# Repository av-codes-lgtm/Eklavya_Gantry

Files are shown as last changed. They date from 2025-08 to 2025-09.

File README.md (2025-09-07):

# **GantryMate-200: Automated Gantry-Based Screwing System**
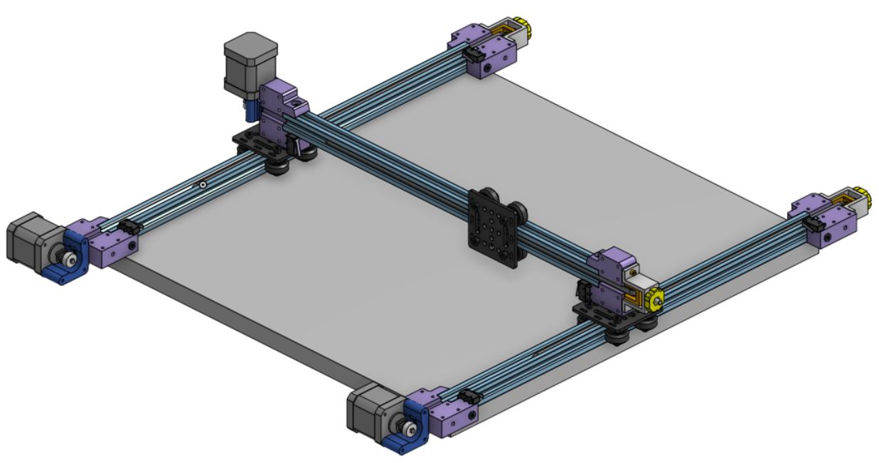
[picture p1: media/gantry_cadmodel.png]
whole assembly_withouttoolhead
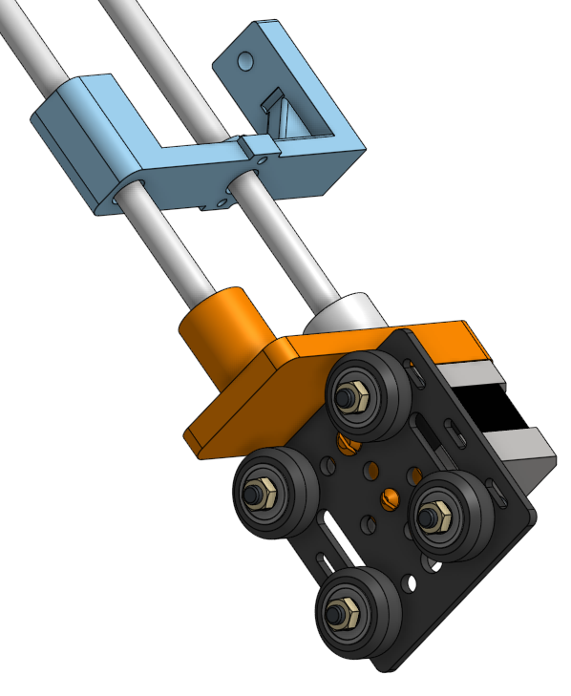
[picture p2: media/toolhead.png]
Toolhead 3d files
|||
:-------------------------:|:-------------------------:|

<p align="center">
  
</p>

## Table of Contents
1. [Problem Statement](#problem-statement)
2. [Our Solution](#our-solution)
   - [LED Panel Configuration](#led-panel-configuration)
   - [Critical Requirements](#critical-requirements)
3. [Features](#features)
4. [Prerequisites](#prerequisites)
5. [Repository Structure](#repository-structure)
6. [Installing](#installing)
7. [Hardware Architecture](#hardware-architecture)
8. [Future Goals](#future-goals)
9. [Authors](#authors)
10. [Acknowledgments](#acknowledgments)

---

## Problem Statement

**GantryMate-200** addresses the challenge of automating the precise handling of **~280 miniature screws (1 mm size)** on sensitive LED panels. The system must operate with extreme precision around delicate circuitry while maintaining high-speed performance.

## Our Solution

An advanced automated gantry system designed for precision screwing and unscrewing of miniature screws on delicate LED panels with sub-millimeter accuracy and high-speed operation.

[CAD MODEL](https://cad.onshape.com/documents/f8e877963d969bd52a009480/w/ae625ac84bd115da8b87aa91/e/6dbc831cc6b275fe37f96716) (Our CAD files)

### LED Panel Configuration

The target LED panel consists of two distinct layers:

* **Top Layer:** Contains **200 screws** - must be removed first during disassembly
* **Bottom Layer:** Contains **80 screws** - accessible only after top layer removal

**Installation Process:** Follows reverse order (bottom layer first, then top layer)

### Critical Requirements

Given the proximity to sensitive circuitry, the system must ensure:

- Sub-millimeter positioning repeatability
- Precise force control to prevent damage
- Accurate screw orientation detection
- Zero tolerance for misalignment
- Complete each screwing/unscrewing operation in **under 5 seconds**

## Features

- **High precision 3-axis gantry system** (X, Y, Z axes)
- **Specialized toolhead** with automated screw feeding mechanism
- **Sub-millimeter(0.05mm resolution) positioning accuracy**
- **High-speed operation** (<5 seconds per screw to be achieved)
- **Automated screw orientation** ensuring correct placement(to be achieved)

### Prerequisites

Hardware requirements:
- ESP32 development board
- DRV8825 stepper motor drivers (3x for X, Y, Z axes)
- Nema 17 Stepper motors (3x for gantry movement)
- Power supply (appropriate voltage/current for your stepper motors)
- Mechanical components (rails, belts, pulleys, frame, etc)

Software used:
- [ESP-IDF](https://docs.espressif.com/projects/esp-idf/en/latest/esp32/get-started/) (development framework) 
- [KiCad](https://www.kicad.org/) (for PCB modifications)
- [Onshape](https://www.onshape.com/) (for Mechanical Design)
- Git for version control.

### Repository Structure

```
Eklavya_Gantry
├── Docs/
├── Firmware/
│   ├── DRV8825/                   #Code for Running the system on DRV8825   
│   │   ├── circle/
│   │   ├── Double_axes/
│   │   ├── final/
│   │   ├── go_to_pos/
│   │   ├── homing/
│   │   ├── limit/
│   │   ├── SRA/
│   │   ├── step_func/
│   │   ├── stepper_test/
│   │   ├── totalhoming/
│   │   └── total_positioning/
│   ├── TMC2208/                   #Code for Running the system on TMC2208
│   │   ├── Go_to_pos/
│   │   ├── step_func/
│   │   └── uart/
│   │       ├── nmea0183_parser/
│   │       ├── uart_async_rxtxtasks/
│   │       ├── uart_echo/
│   │       ├── uart_echo_rs485/
│   │       ├── uart_events/
│   │       ├── uart_repl/
│   │       └── uart_select/
│   └── Screwdriver/               #Code for operating the toolhead
│       └── Screw/
├── Mechanics/
│   .
│   .
│   └── STL files for 3D Printed parts
├── PCB/
|   .
|   .
|   └── KiCad Files for PCB
└── README.md

```

### Installing

Step-by-step setup process:

1. **Clone the repository**
```bash
git clone https://github.com/av-codes-lgtm/Eklavya_Gantry.git
cd Eklavya_Gantry
```

2. **Build and flash firmware**

Go to the folder with the code you want to flash to the esp using 

```bash
cd /Eklavya_Gantry/Firmware/folder-of-your-choice
```

and then run the following code

```bash
idf.py build flash monitor
```

## Hardware Architecture

| Component | Description |
|---|---|
| [ESP32](https://www.espressif.com/en/products/socs/esp32) | Main microcontroller with WiFi/Bluetooth capability |
| [DRV8825 Stepper Drivers](https://www.pololu.com/product/2133) | High-performance microstepping motor drivers |
| Nema 17 Stepper Motors | Precision motors for X, Y, Z axis control |
| Custom PCB | Integrated control and driver circuitry (under development) |

## Future Goals
- Shift to TMC2208 stepper drivers for better current handling and power distribution. DRV8825 does not work for prolonged time periods.
- Finalising the circuitry and shifting completely to PCB.
- Fine tuning the screw in and screw out processes to achieve industry grade quality screwing.
- Add a screw feeding system for the "screwing in" process.
- Creating a feedback mechanism to verify Screwing and unscrewing
- Creating a UI (Either WebPortal or build in software controlled using Raspberry Pi and a small screen) to make operation of the system simpler.
## Authors
*  *Firmware and Hardware setup*- [Aryan_Vyapari](https://github.com/av-codes-lgtm)
*  *PCB Design and tool-head operation* - [Sarvaarth_Narang](https://github.com/SarvaarthN)
*  *Firmware and Hardware setup* - [Pushkar_Dube](https://github.com/pushkardube)  

See the list of [contributors](https://github.com/av-codes-lgtm/Eklavya_Gantry/graphs/contributors) who participated in this project.
## Acknowledgments

* Thanks to the ESP-IDF, KiCad and Onshape community for excellent development tools
* Inspiration from industrial automation and precision manufacturing
- Thanks to our Robotics Club [SRA-VJTI](https://github.com/sra-vjti)  
* Special thanks to our senior mentors [Amey_Tikhe](https://github.com/AmeyaTikhe)  &  [Varun_Nigudkar](https://github.com/fluffysunfish?tab=overview&from=2024-12-01&to=2024-12-31)  

---

**For technical support, feature requests, or bug reports, please open an issue on GitHub.**

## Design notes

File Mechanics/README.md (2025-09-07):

## Mechanics

Stl files of the 3D printed parts & some CAD models

Gantry
toolhead
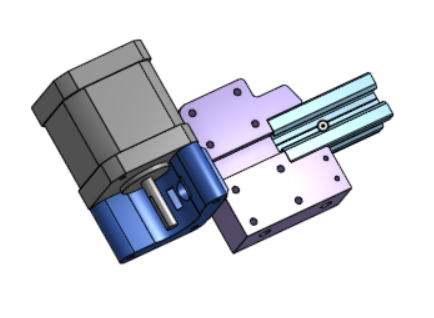
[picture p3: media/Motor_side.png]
motor_supports

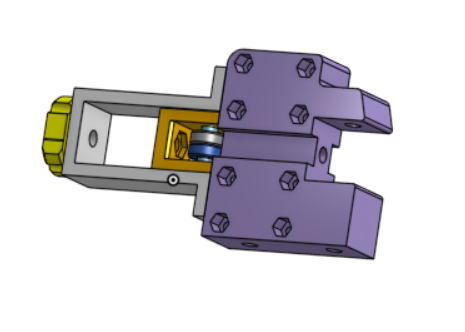
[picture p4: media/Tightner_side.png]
pulley_supports

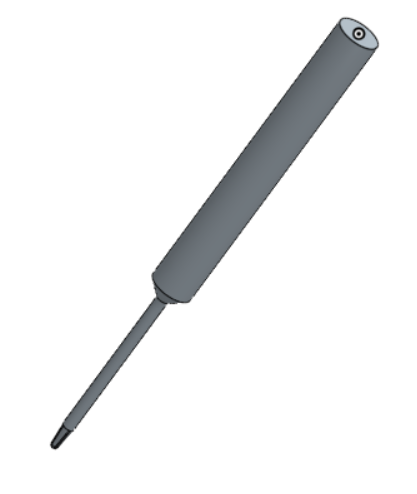
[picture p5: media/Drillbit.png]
Drillbit

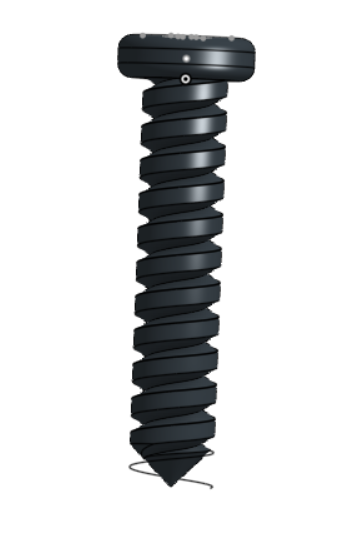
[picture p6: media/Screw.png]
Screws


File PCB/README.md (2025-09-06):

# DRV8825 Stepper Motor Driver with ESP32 and Limit Switch

This project demonstrates how to control a stepper motor using an **ESP32**, a **DRV8825 motor driver**, and a **limit switch** for homing or safety purposes. 
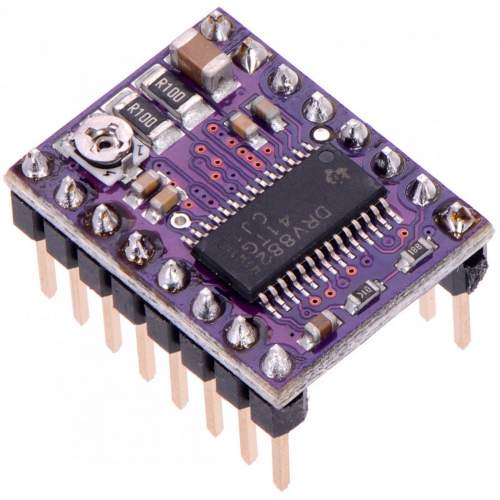
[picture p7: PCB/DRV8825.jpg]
DRV8825 Motor Driver

---

## Circuit Description

The **ESP32** sends step and direction signals to the **DRV8825**, which drives a bipolar stepper motor.  
A **limit switch** is added to detect the end position or provide a safe stop.

---

## Connections

### DRV8825 → Stepper Motor
- **A1, A2, B1, B2** → Connect to stepper motor coils  
  - A coil: A1, A2  
  - B coil: B1, B2  

### DRV8825 → ESP32
- **STEP** → GPIO 18 (pulse to step motor)  
- **DIR** → GPIO 19 (sets rotation direction)  
- **EN (Enable)** → GPIO 21 (active LOW, optional)  
- **GND** → ESP32 GND  
- **VMOT** → External motor supply (8.2–45V depending on motor) but for this Project 12V was used
- **GND (Motor)** → Power supply ground  

**Important:** Place a 100µF electrolytic capacitor across VMOT and GND close to the DRV8825 to protect against voltage spikes.  

### Limit Switch → ESP32
- One terminal → GPIO 23  
- Other terminal → GND  
- Use **internal pull-up resistor** in ESP32 code.  

---

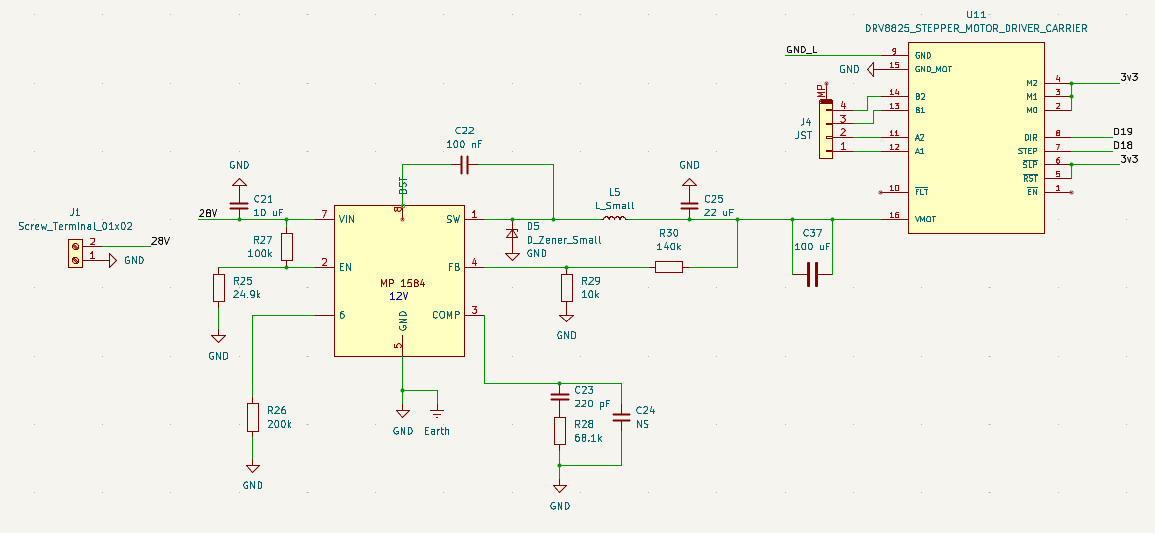
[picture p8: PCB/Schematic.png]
PCB Schematic
 

## Circuit Diagram

```plaintext
              +-------------------+
   VMOT 8-45V |                   | Stepper Motor
   + ---------| VMOT        A1 ---|---- Coil A
   - ---------| GND         A2 ---|---- Coil A
              |                   |
ESP32 GPIO 18 | STEP        B1 ---|---- Coil B
ESP32 GPIO 19 | DIR         B2 ---|---- Coil B
ESP32 GPIO 21 | EN                |
ESP32   GND - | GND               |
              +-------------------+

Limit Switch:
  GPIO 23 ---/ ---- GND

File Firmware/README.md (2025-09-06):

# Gantry Motion Control

This repository contains firmware and test programs for a **3-axis gantry-style screwing machine**, supporting multiple stepper motor drivers (DRV8825 and TMC2208).  
The codebase is organized into modules for motion control, homing, positioning, and testing.

---

## 📂 Repository Structure

### Root Folders
- **.vscode/**  
  VSCode project settings.

- **DRV8825/**  
  Codebase for the gantry using the **DRV8825 stepper driver**.

- **TMC2208/**  
  Codebase for the gantry using the **TMC2208 stepper driver**.

- **Screwdriver/**  
  Code for screwdriver(geared DC motor).
---
### Inside `DRV8825/`

Each driver folder contains multiple subfolders for different functionalities:

- **Double_axes/**  
  Control programs for two axes working together.

- **SRA/**  
  Plots “SRA” on the plane using the gantry

- **circle/**  
  Code for drawing/controlling circular motion.

- **final/**  
  Final stable build for **3-axis gantry motion control**.

- **go_to_pos/**  
  Precise linear positioning of one axis.

- **homing/**  
  Executes homing in one axis.

- **limit/**  
  Test programs for Limit switch functionality.

- **step_func/**  
  Test programs for verifying Acceleration and Deceleration. 

- **stepper_test/**  
  Test programs for verifying stepper motor functionality.

- **total_positioning/**  
  Precise 2D positioning across the plane.

- **totalhoming/**  
  Executes Homing in all axes of the gantry simultaneously

---
### Inside `TMC2208/`

This folder contains code specific to the **TMC2208 stepper driver**:

- **Go_to_pos/**
  Moves the gantry to a specified position.
    
- **step_func/**
  Basic testing for stepper stepping functions.
   
- **uart/**
  UART codes for TMC2208.
---
### Inside `Screwdriver/`

- **Screw/**  
  Contains code for operating a **geared DC motor** (screwdriver mechanism), separate from the stepper-driven gantry system.

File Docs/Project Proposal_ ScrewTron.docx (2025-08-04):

## Project Proposal: ScrewTron – Automated Screwing System for LED Panels

### Problem Statement

The objective is to develop an automated gantry-based system, ScrewTron, capable of screwing and unscrewing approximately 280 miniature screws (1 mm size) on an LED panel efficiently and safely. The system must ensure that each screw is installed or removed in under 5 seconds, while maintaining high precision and avoiding damage to sensitive circuitry.

The panel has two layers:

- The top layer contains 200 screws, which need to be removed first.
- Upon removal, the bottom layer with 80 additional screws becomes accessible.
- The screwing-in process follows the reverse order: the bottom layer is fastened first, followed by the top layer.

Due to the small size of the screws and their close proximity to delicate circuitry, excessive pressure or misalignment can lead to permanent damage. Therefore, the system must prioritize precision, controlled force application, and accurate screw placement and orientation.

### Project Description

The proposed system will feature a high-precision gantry mechanism capable of three-axis motion (X, Y, Z), equipped with a specialized toolhead for screwing/unscrewing operations. A screw feeding mechanism will supply screws to the toolhead in the correct orientation, ensuring uninterrupted operation. The system will be optimized for speed, safety, and accuracy, with the ability to repeat tasks with sub-millimeter precision.

### Key Challenges

1. Screw Feeding Mechanism Designing an efficient feeder that delivers 1 mm screws in the correct orientation to the toolhead without jamming or misalignment.
2. X-Y Gantry Motion Implementing precise and smooth movement across the horizontal plane to position the toolhead at each screw location accurately.
3. Z-Axis Control Ensuring vertical movement of the toolhead is finely controlled to insert or extract screws to the appropriate depth without over-torquing.
4. Time Optimization Ensuring that each screwing/unscrewing operation is completed in less than 5 seconds, keeping the total operation time within practical limits.
5. Toolhead Design and Control Engineering a lightweight, compact, and torque-sensitive toolhead suitable for handling 1 mm screws without damaging surrounding components.

### Major Milestones

- Development of Precision Gantry System Design and implementation of a motion control system with high accuracy in X, Y, and Z directions based on command inputs.
- Design and Testing of Screw Feeder Creation of a reliable mechanism that feeds 1 mm screws in the correct orientation and at appropriate timing.
- Toolhead Integration and Control Design of a screwing/unscrewing toolhead with depth control, torque regulation, and compatibility with the screw feeder.
- System Calibration and Optimization Fine-tuning the system to meet time and precision requirements, ensuring safe operation near delicate electronic components.

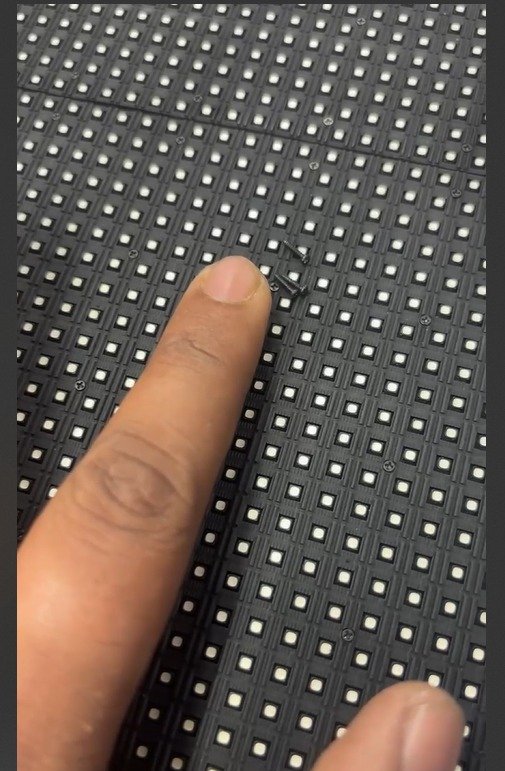
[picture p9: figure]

Video for Reference.mp4 (https://drive.google.com/file/d/1dqILX8j8XaAps2jnEO2ClbA-CurU9LIB/view?usp=sharing)

Only Screwing and unscrewing needs to be automated. Removal of Meshes and frames will be done manually

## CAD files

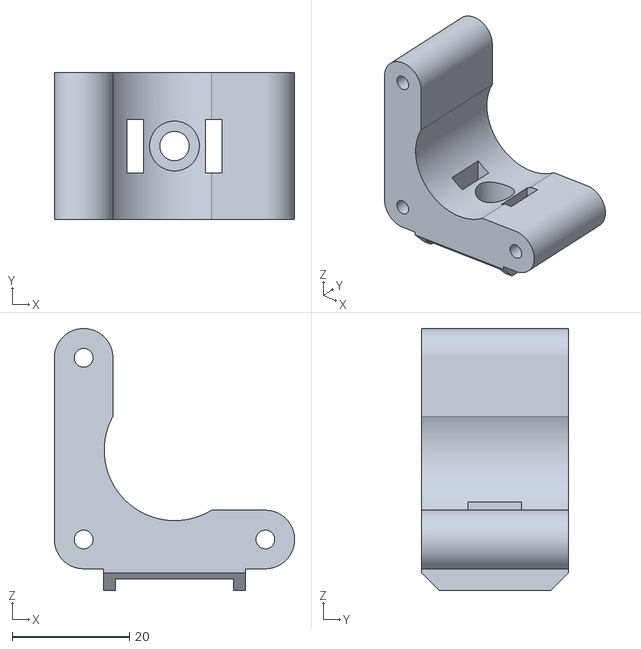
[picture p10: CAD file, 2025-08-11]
Mechanics/x-moteur - support moteur.stl
41.0 x 25.0 x 44.7

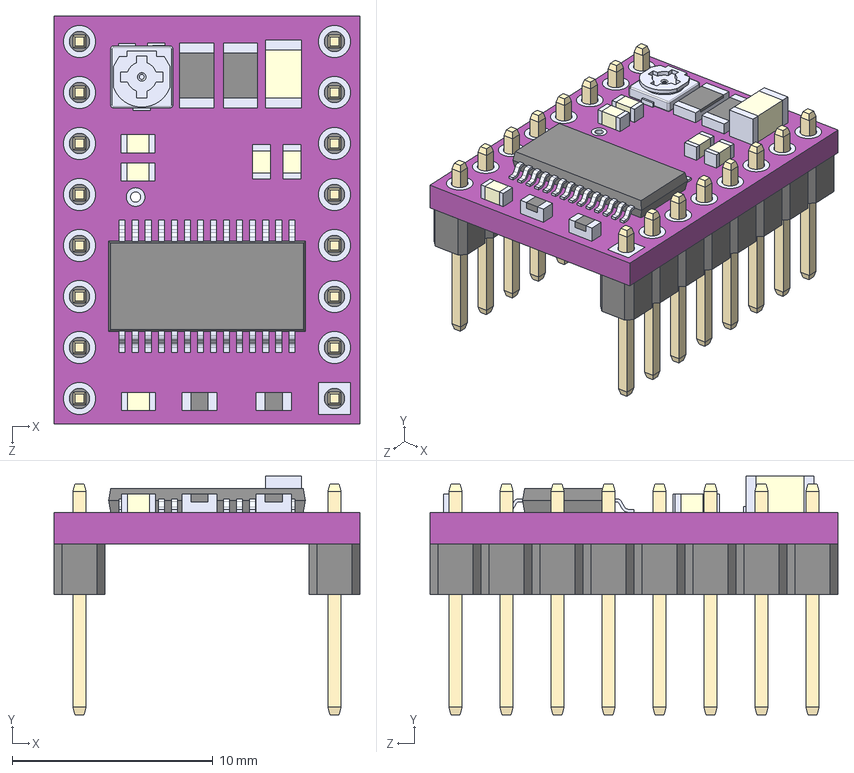
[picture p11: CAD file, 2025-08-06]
PCB/DRV8825_STEPPER_MOTOR_DRIVER_CARRIER.step
15.2 x 11.9 x 20.3 mm

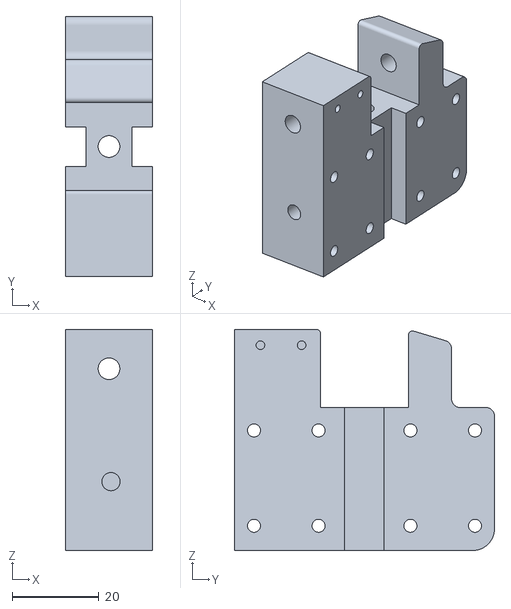
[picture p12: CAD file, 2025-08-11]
Mechanics/x-moteur - support paliers L.stl
20.0 x 60.0 x 51.0

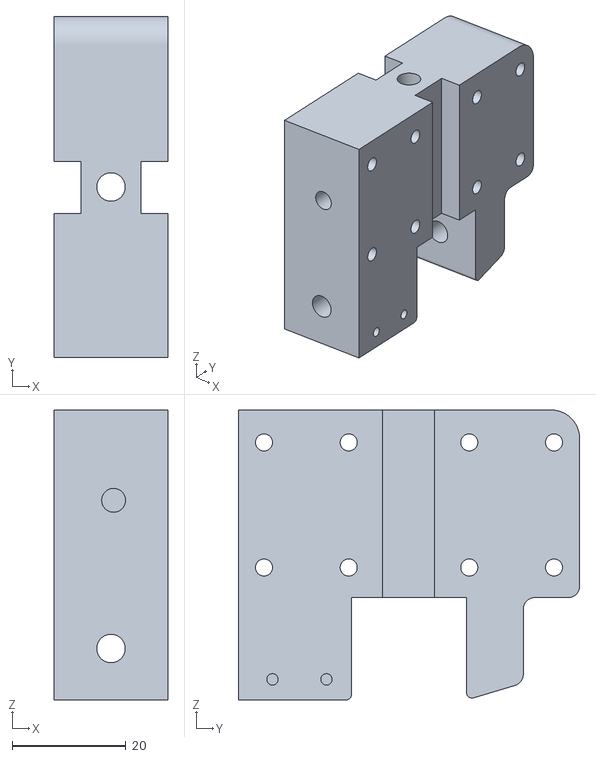
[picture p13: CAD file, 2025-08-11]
Mechanics/x-moteur - support_palier_R.stl
20.0 x 60.0 x 51.0

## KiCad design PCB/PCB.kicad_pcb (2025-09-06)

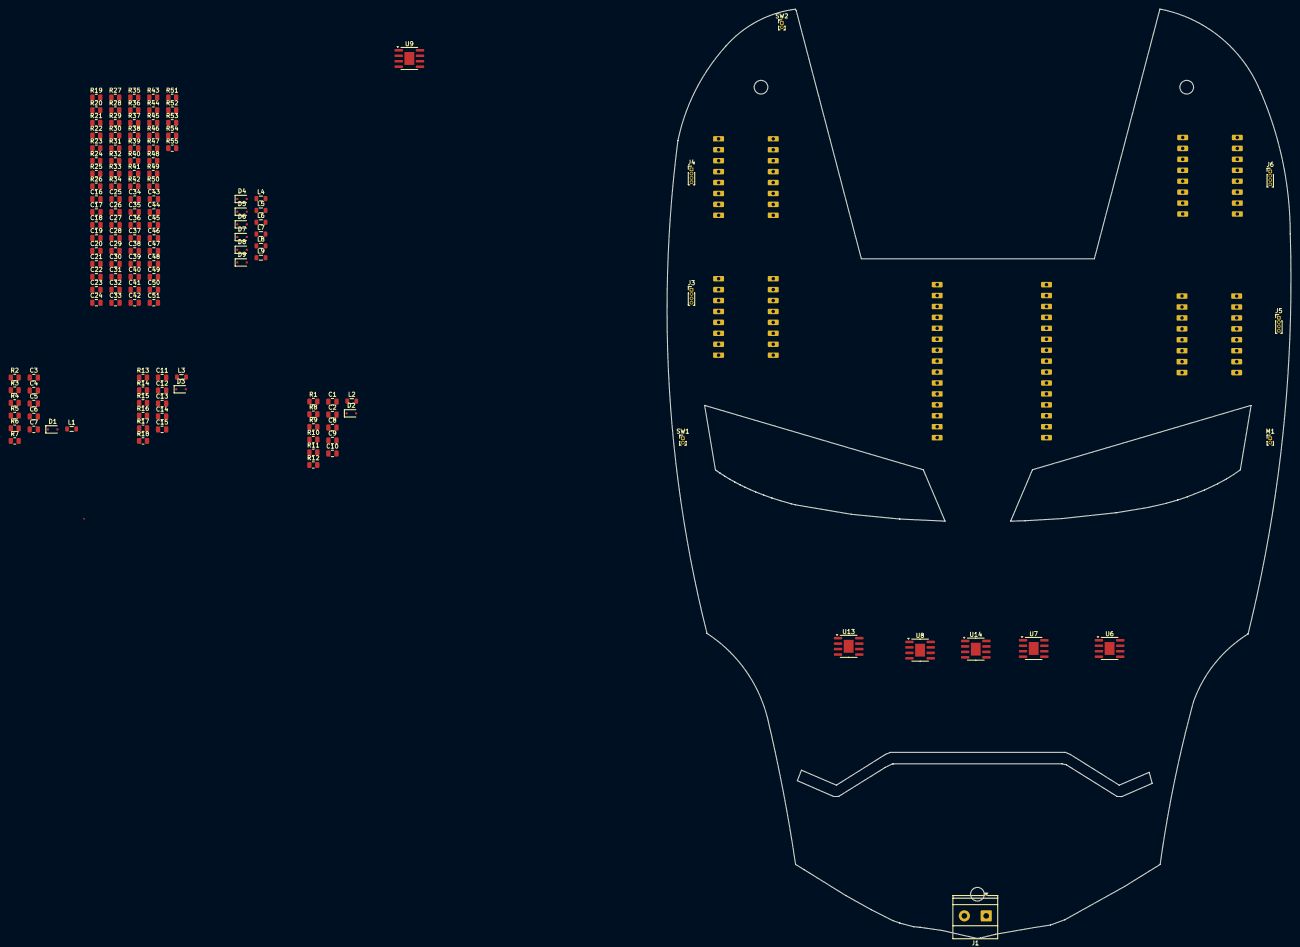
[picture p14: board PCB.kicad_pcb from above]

Board: 2 copper layers, 145.0 x 216.0 mm, 143 parts (0 on the bottom side), 82 nets.

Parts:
C1, C7, C11, C16, C21, C26, C31, C39, C46: 10 uF; C_0805_2012Metric
C2, C3, C12, C17, C22, C27, C32, C40, C47: 100 nF; C_0805_2012Metric
C4, C10, C15, C20, C25, C30, C35, C43, C50: 22 uF; C_0805_2012Metric
C5, C8, C13, C18, C23, C28, C33, C41, C48: 220 pF; C_0805_2012Metric
C6, C9, C14, C19, C24, C29, C34, C42, C49: NS; C_0805_2012Metric
C36, C37, C38, C44, C51: 100 uF; C_0805_2012Metric
C45: 0.1 uF; C_0805_2012Metric
D1, D2, D3, D4, D5, D6, D7, D8, D9: D_Zener_Small; D_SOD-323F
J1: Screw_Terminal_01x02; TerminalBlock_Phoenix_MKDS-1,5-2-5.08_1x02_P5.08mm_Horizont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
J2: esp32 30 pin; ESP32 30 pin
J3, J4, J5, J6: JST; PinHeader_1x04_P1.00mm_Vertical
L1, L2, L3, L4, L5, L6, L7, L8, L9: L_Small; L_0805_2012Metric
M1: Motor_DC; PinHeader_1x02_P1.00mm_Vertical
R1, R7, R13, R19, R25, R31, R37, R43, R50: 24.9k; R_0805_2012Metric
R2, R18, R24, R30, R36, R48, R55: 140k; R_0805_2012Metric
R3, R17, R23, R29, R35, R47, R54: 10k; R_0805_2012Metric
R4, R10, R16, R22, R28, R34, R40, R46, R53: 68.1k; R_0805_2012Metric
R5, R8, R14, R20, R26, R32, R38, R44, R51: 200k; R_0805_2012Metric
R6, R9, R15, R21, R27, R33, R39, R45, R52: 100k; R_0805_2012Metric
R11, R41: 4.3k; R_0805_2012Metric
R12, R42: 22k; R_0805_2012Metric
R49: 0.1 k; R_0805_2012Metric
SW1, SW2: SW_SPDT_XKB_DMx-xxxx-1; PinHeader_1x02_P1.00mm_Vertical
U6, U7, U8, U9, U13, U14: SOIC-8-1EP_3.9x4.9mm_P1.27mm_EP2.29x3mm
U10, U11, U12, U15: DRV8825_STEPPER_MOTOR_DRIVER_CARRIER; DRV8825Module

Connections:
/Assembly/3v3: J2.16 (3V3), SW1.1 (A), SW2.1 (A), U10.2 (M0), U10.3 (M1), U10.4 (M2), U10.5 (~RST), U10.6 (~SLP), U11.2 (M0), U11.3 (M1), U11.4 (M2), U11.5 (~RST), U11.6 (~SLP), U12.2 (M0), U12.3 (M1), U12.4 (M2), U12.5 (~RST), U12.6 (~SLP), U15.2 (M0), U15.3 (M1), U15.4 (M2), U15.5 (~RST), U15.6 (~SLP)
/Assembly/28V: C16.2, C21.2, C26.2, C31.2, C39.2, C46.2, J1.2, R21.1, R27.1, R33.1, R39.1, R45.1, R52.1, U6.7 (VIN), U7.7 (VIN), U8.7 (VIN), U9.7 (VIN), U13.7 (VIN), U14.7 (VIN)
/Assembly/D2: J2.19 (D2), U10.7 (STEP), U15.8 (DIR)
/Assembly/D4: J2.20 (D4), U10.8 (DIR), U15.7 (STEP)
/Assembly/D18: J2.24 (D18), U11.7 (STEP)
/Assembly/D19: J2.25 (D19), U11.8 (DIR)
/Assembly/GND_L: J2.17 (GND), U10.9 (GND), U11.9 (GND), U12.9 (GND), U15.9 (GND)
Earth: C1.1, C4.1, C6.2, C7.1, C9.2, C10.1, C11.1, C14.2, C15.1, C16.1, C19.2, C20.1, C21.1, C24.2, C25.1, C26.1, C29.2, C30.1, C31.1, C34.2, C35.1, C39.1, C42.2, C43.1, C46.1, C49.2, C50.1, D1.2 (A), D2.2 (A), D3.2 (A), D4.2 (A), D5.2 (A), D6.2 (A), D7.2 (A), D8.2 (A), D9.2 (A), J1.1, M1.2 (-), R1.2, R3.2, R4.2, R5.2, R7.2, R8.2, R10.2, R11.2, R13.2, R14.2, R16.2, R17.2, R19.2, R20.2, R22.2, R23.2, R25.2, R26.2, R28.2, R29.2, R31.2, R32.2, R34.2, R35.2, R37.2, R38.2, R40.2, R41.2, R43.2, R44.2, R46.2, R47.2, R49.2, R50.2, R51.2, R53.2, R54.2, U6.5 (GND), U7.5 (GND), U8.5 (GND), U9.5 (GND), U10.15 (GND_MOT), U11.15 (GND_MOT), U12.15 (GND_MOT), U13.5 (GND), U14.5 (GND), U15.15 (GND_MOT)
unnamed: C4.2, L1.2, R2.2
unnamed: C5.2, R4.1
unnamed: C8.2, R10.1
unnamed: C10.2, L2.2, R12.2
unnamed: C13.2, R16.1
unnamed: C15.2, L3.2, R18.2
unnamed: C18.2, R22.1
unnamed: C23.2, R28.1
unnamed: C28.2, R34.1
unnamed: C33.2, R40.1
unnamed: C41.2, R46.1
unnamed: C45.2, R49.1
unnamed: C48.2, R53.1
unnamed: C3.2, D1.1 (K), L1.1
unnamed: C2.2, D2.1 (K), L2.1
unnamed: C12.2, D3.1 (K), L3.1
unnamed: C17.2, D4.1 (K), L4.1, U6.1 (SW)
unnamed: C22.2, D5.1 (K), L5.1, U7.1 (SW)
unnamed: C27.2, D6.1 (K), L6.1, U8.1 (SW)
unnamed: C32.2, D7.1 (K), L7.1, U9.1 (SW)
unnamed: C40.2, D8.1 (K), L8.1, U13.1 (SW)
unnamed: C47.2, D9.1 (K), L9.1, U14.1 (SW)
unnamed: C35.2, L7.2, R42.2
unnamed: J3.1, U10.12 (A1)
unnamed: J3.2, U10.11 (A2)
unnamed: J3.3, U10.13 (B1)
unnamed: J3.4, U10.14 (B2)
unnamed: J4.1, U11.12 (A1)
unnamed: J4.2, U11.11 (A2)
unnamed: J4.3, U11.13 (B1)
unnamed: J4.4, U11.14 (B2)
unnamed: J5.1, U12.12 (A1)
unnamed: J5.2, U12.11 (A2)
unnamed: J5.3, U12.13 (B1)
unnamed: J5.4, U12.14 (B2)
unnamed: J6.1, U15.12 (A1)
unnamed: J6.2, U15.11 (A2)
unnamed: J6.3, U15.13 (B1)
unnamed: J6.4, U15.14 (B2)
unnamed: C43.2, C44.1, C44.2, C45.1, L8.2, M1.1 (+), R48.2
unnamed: C8.1, C9.1
unnamed: R1.1, R9.2
unnamed: R11.1, R12.1
unnamed: C1.2, R9.1
unnamed: C5.1, C6.1
unnamed: R6.2, R7.1
unnamed: R2.1, R3.1
unnamed: C7.2, R6.1
unnamed: C13.1, C14.1
unnamed: R13.1, R15.2
unnamed: R17.1, R18.1
unnamed: C11.2, R15.1
unnamed: C18.1, C19.1, U6.3 (COMP)
unnamed: R19.1, R21.2, U6.2 (EN)
unnamed: R23.1, R24.1, U6.4 (FB)
unnamed: C23.1, C24.1, U7.3 (COMP)
unnamed: R25.1, R27.2, U7.2 (EN)
unnamed: R29.1, R30.1, U7.4 (FB)
unnamed: C28.1, C29.1, U8.3 (COMP)
unnamed: R31.1, R33.2, U8.2 (EN)
unnamed: R35.1, R36.1, U8.4 (FB)
unnamed: R37.1, R39.2, U9.2 (EN)
unnamed: C33.1, C34.1, U9.3 (COMP)
unnamed: R41.1, R42.1, U9.4 (FB)
unnamed: C20.2, C36.1, C36.2, L4.2, R24.2, U10.16 (VMOT)
unnamed: C25.2, C37.1, C37.2, L5.2, R30.2, U11.16 (VMOT)
unnamed: C30.2, C38.1, C38.2, L6.2, R36.2, U12.16 (VMOT)
unnamed: C41.1, C42.1, U13.3 (COMP)
unnamed: R43.1, R45.2, U13.2 (EN)
unnamed: R47.1, R48.1, U13.4 (FB)
unnamed: C48.1, C49.1, U14.3 (COMP)
unnamed: R50.1, R52.2, U14.2 (EN)
unnamed: R54.1, R55.1, U14.4 (FB)
unnamed: C50.2, C51.1, C51.2, L9.2, R55.2, U15.16 (VMOT)

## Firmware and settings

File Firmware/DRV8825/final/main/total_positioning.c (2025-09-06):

#include "freertos/FreeRTOS.h"
#include "freertos/task.h"
#include "driver/gpio.h"
#include "driver/uart.h"
#include "esp_rom_sys.h"
#include <stdio.h>
#include <stdlib.h>
#include <math.h>

#define X_STEP_PIN GPIO_NUM_12
#define X_DIR_PIN  GPIO_NUM_14
#define Y_STEP_PIN GPIO_NUM_23
#define Y_DIR_PIN  GPIO_NUM_22
#define Z_STEP_PIN GPIO_NUM_26
#define Z_DIR_PIN  GPIO_NUM_25

#define M0_PIN  GPIO_NUM_19
#define M1_PIN  GPIO_NUM_18
#define M2_PIN  GPIO_NUM_5

#define EnablePIN GPIO_NUM_4
#define PIN1 GPIO_NUM_16
#define PIN2 GPIO_NUM_17

#define X_LIM_SWITCH_PIN  GPIO_NUM_15
#define Y_LIM_SWITCH_PIN  GPIO_NUM_13
// #define Z_LIM_SWITCH_PIN  GPIO_NUM_
#define LIM_ACTIVE_LEVEL  0

#define STEP_PULSE_HIGH_US 5
#define MAX_STEP_INTERVAL_US 150
#define MIN_STEP_INTERVAL_US 30

#define STEP_HIGH_TIME_uS 5
#define STEP_TOTAL_TIME_uS 30

#define PULLEY_RADIUS_MM 6.36
#define STEPS_PER_REV 3200
#define PI 6.28318530717958647692/2
#define STEPS_PER_MM ( (double)STEPS_PER_REV / (PI * (double)PULLEY_RADIUS_MM) )

#define X_MAX_MM 540
#define Y_MAX_MM 390

static volatile int current_x_mm = 0;
static volatile int current_y_mm = 0;

static inline void step_pulse(gpio_num_t step_pin) {
    gpio_set_level(step_pin, 1);
    esp_rom_delay_us(STEP_PULSE_HIGH_US);
    gpio_set_level(step_pin, 0);
}

static void setup_stepper_pins(void) {
    gpio_config_t io_conf_out = {
        .intr_type = GPIO_INTR_DISABLE,
        .mode = GPIO_MODE_OUTPUT,
        .pin_bit_mask =
            (1ULL << X_STEP_PIN) | (1ULL << X_DIR_PIN) |
            (1ULL << Y_STEP_PIN) | (1ULL << Y_DIR_PIN) |
            (1ULL << Z_STEP_PIN) | (1ULL << Z_DIR_PIN) |
            (1ULL << EnablePIN) | (1ULL << PIN1) | (1ULL << PIN2) |
            (1ULL << M0_PIN) | (1ULL << M1_PIN) | (1ULL << M2_PIN),
        .pull_down_en = 0,
        .pull_up_en = 0
    };
    gpio_config(&io_conf_out);

    gpio_config_t io_conf_in = {
        .intr_type = GPIO_INTR_DISABLE,
        .mode = GPIO_MODE_INPUT,
        .pin_bit_mask = (1ULL << X_LIM_SWITCH_PIN) | (1ULL << Y_LIM_SWITCH_PIN) ,
        .pull_down_en = 0,
        .pull_up_en = 1
    };
    gpio_config(&io_conf_in);
}

static void setup_uart(void) {
    const uart_config_t uart_config = {
        .baud_rate = 115200,
        .data_bits = UART_DATA_8_BITS,
        .parity = UART_PARITY_DISABLE,
        .stop_bits = UART_STOP_BITS_1,
        .flow_ctrl = UART_HW_FLOWCTRL_DISABLE
    };
    uart_driver_install(UART_NUM_0, 1024, 0, 0, NULL, 0);
    uart_param_config(UART_NUM_0, &uart_config);
    uart_set_pin(UART_NUM_0, UART_PIN_NO_CHANGE, UART_PIN_NO_CHANGE, UART_PIN_NO_CHANGE, UART_PIN_NO_CHANGE);
}

static int uart_read_int_blocking(void) {
    char buf[32] = {0};
    int idx = 0;
    uint8_t ch;
    while (idx < (int)sizeof(buf) - 1) {
        int len = uart_read_bytes(UART_NUM_0, &ch, 1, portMAX_DELAY);
        if (len > 0) {
            if (ch == '\n' || ch == '\r') break;
            buf[idx++] = (char)ch;
            uart_write_bytes(UART_NUM_0, (const char *)&ch, 1);
        }
    }
    buf[idx] = '\0';
    return atoi(buf);
}

static inline int mm_to_steps(double mm) {
    double s = mm * STEPS_PER_MM;
    return (int)llround(s);
}

static inline int read_limit(gpio_num_t pin) {
    return gpio_get_level(pin);
}

static void home_axis(gpio_num_t step_pin, gpio_num_t dir_pin, gpio_num_t lim_pin, int *current_mm) {
    gpio_set_level(dir_pin, 0);
    int guard_steps = mm_to_steps( (double)(X_MAX_MM + Y_MAX_MM) * 2.0 );
    while (read_limit(lim_pin) != LIM_ACTIVE_LEVEL && guard_steps-- > 0) {
        step_pulse(step_pin);
        esp_rom_delay_us(MAX_STEP_INTERVAL_US);
    }
    vTaskDelay(pdMS_TO_TICKS(50));
    if (read_limit(lim_pin) != LIM_ACTIVE_LEVEL) {
        printf("\n[WARN] Homing failed on pin %d (limit not triggered)\n", (int)lim_pin);
    }
    *current_mm = 0;
}

static void home_all(void) {
    home_axis(X_STEP_PIN, X_DIR_PIN, X_LIM_SWITCH_PIN, (int*)&current_x_mm);
    home_axis(Y_STEP_PIN, Y_DIR_PIN, Y_LIM_SWITCH_PIN, (int*)&current_y_mm);
    // home_axis(Z_STEP_PIN, Z_DIR_PIN, Z_LIM_SWITCH_PIN, (int*)&current_x_mm);
}

static void line_move_mm_blocking(int target_x_mm, int target_y_mm) {
    if (target_x_mm < 0) target_x_mm = 0;
    if (target_y_mm < 0) target_y_mm = 0;
    if (target_x_mm > X_MAX_MM) target_x_mm = X_MAX_MM;
    if (target_y_mm > Y_MAX_MM) target_y_mm = Y_MAX_MM;

    int dx_mm = target_x_mm - current_x_mm;
    int dy_mm = target_y_mm - current_y_mm;

    int sx = (dx_mm >= 0) ? 1 : -1;
    int sy = (dy_mm >= 0) ? 1 : -1;

    int dx_steps = abs(mm_to_steps((double)dx_mm));
    int dy_steps = abs(mm_to_steps((double)dy_mm));

    if (dx_steps == 0 && dy_steps == 0) return;

    gpio_set_level(X_DIR_PIN, (sx > 0) ? 1 : 0);
    gpio_set_level(Y_DIR_PIN, (sy > 0) ? 1 : 0);

    int primary = (dx_steps >= dy_steps) ? dx_steps : dy_steps;
    int accel_steps = (int)llround(0.2 * (double)primary);
    if (accel_steps < 1) accel_steps = (primary >= 3) ? 1 : 0;
    int decel_steps = accel_steps;
    int const_steps = primary - accel_steps - decel_steps;
    if (const_steps < 0) { const_steps = 0; accel_steps = primary / 2; decel_steps = primary - accel_steps; }

    int err = (dx_steps >= dy_steps) ? (dx_steps / 2) : (dy_steps / 2);
    int x_cnt = 0, y_cnt = 0;

    for (int i = 0; i < primary; i++) {
        if (dx_steps >= dy_steps) {
            err -= dy_steps;
            if (err < 0) { err += dx_steps; step_pulse(Y_STEP_PIN); y_cnt++; }
            step_pulse(X_STEP_PIN); x_cnt++;
        } else {
            err -= dx_steps;
            if (err < 0) { err += dy_steps; step_pulse(X_STEP_PIN); x_cnt++; }
            step_pulse(Y_STEP_PIN); y_cnt++;
        }

        if ((read_limit(X_LIM_SWITCH_PIN) == LIM_ACTIVE_LEVEL && sx < 0) ||
            (read_limit(Y_LIM_SWITCH_PIN) == LIM_ACTIVE_LEVEL && sy < 0)) {
            printf("\n[HALT] Hit limit during move.\n");
            break;
        }

        int interval_us = MAX_STEP_INTERVAL_US;
        if (i < accel_steps && accel_steps > 0) {
            interval_us = MAX_STEP_INTERVAL_US - (int)((double)(MAX_STEP_INTERVAL_US - MIN_STEP_INTERVAL_US) * (double)i / (double)accel_steps);
        } else if (i >= accel_steps + const_steps && decel_steps > 0) {
            int di = i - (accel_steps + const_steps);
            interval_us = MIN_STEP_INTERVAL_US + (int)((double)(MAX_STEP_INTERVAL_US - MIN_STEP_INTERVAL_US) * (double)di / (double)decel_steps);
        } else {
            interval_us = MIN_STEP_INTERVAL_US;
        }
        if (interval_us < STEP_PULSE_HIGH_US + 1) interval_us = STEP_PULSE_HIGH_US + 1;
        esp_rom_delay_us(interval_us - STEP_PULSE_HIGH_US);
    }

    current_x_mm += sx * (int)llround((double)x_cnt / STEPS_PER_MM);
    current_y_mm += sy * (int)llround((double)y_cnt / STEPS_PER_MM);
    if (current_x_mm < 0) current_x_mm = 0;
    if (current_y_mm < 0) current_y_mm = 0;
    if (current_x_mm > X_MAX_MM) current_x_mm = X_MAX_MM;
    if (current_y_mm > Y_MAX_MM) current_y_mm = Y_MAX_MM;
}

void step(int no_steps) {
    int accel_steps = 6400;
    int decel_steps = accel_steps;
    if (no_steps<accel_steps){
        accel_steps=no_steps/2;
        decel_steps=accel_steps;
    }
    int const_steps = no_steps - accel_steps - decel_steps;
    if (const_steps<0){
        const_steps=0;
    }
    // Define min and max total step time (in microseconds)
    int min_step_time = 30;  // Fastest (small delay between steps)
    int max_step_time = 150; // Slowest (long delay between steps)

    // Acceleration Phase
    for (int i = 0; i < accel_steps; i++) {
        int step_time = max_step_time - ((max_step_time - min_step_time) * i / accel_steps);
        gpio_set_level(Z_STEP_PIN, 1);
        esp_rom_delay_us(STEP_HIGH_TIME_uS);
        gpio_set_level(Z_STEP_PIN, 0);
        esp_rom_delay_us(step_time - STEP_HIGH_TIME_uS);
    }

    // Constant Speed Phase
    for (int i = 0; i < const_steps; i++) {
        gpio_set_level(Z_STEP_PIN, 1);
        esp_rom_delay_us(STEP_HIGH_TIME_uS);
        gpio_set_level(Z_STEP_PIN, 0);
        esp_rom_delay_us(min_step_time - STEP_HIGH_TIME_uS);
    }

    // Deceleration Phase
    for (int i = 0; i < decel_steps; i++) {
        int step_time = min_step_time + ((max_step_time - min_step_time) * i / decel_steps);
        gpio_set_level(Z_STEP_PIN, 1);
        esp_rom_delay_us(STEP_HIGH_TIME_uS);
        gpio_set_level(Z_STEP_PIN, 0);
        esp_rom_delay_us(step_time - STEP_HIGH_TIME_uS);
    }
}

void app_main(void) {
    setup_stepper_pins();
    setup_uart();

    gpio_set_level(M0_PIN, 1);
    gpio_set_level(M1_PIN, 0);
    gpio_set_level(M2_PIN, 1);

    printf("\nHoming...\n");
    home_all();
    vTaskDelay(pdMS_TO_TICKS(200));

    while (1) {
        printf("\nEnter X (mm, 0-%d): ", X_MAX_MM);
        int tx = uart_read_int_blocking();
        printf("\nEnter Y (mm, 0-%d): ", Y_MAX_MM);
        int ty = uart_read_int_blocking();
        printf("\nEnter Z action (0 = Screw, 1 = Unscrew): ");
        int tz = uart_read_int_blocking();

        if (tz != 0 && tz != 1) {
            printf("\nInvalid Z action! Please enter 0 or 1.\n");
            // you can choose to re-prompt here if needed
        }

        if (tx < 0 || ty < 0 || tx > X_MAX_MM || ty > Y_MAX_MM) {
            printf("\nError: target out of bounds\n");
            continue;
        }

        line_move_mm_blocking(tx, ty);
        if (tz == 0){
            gpio_set_level(Z_DIR_PIN, 0); // Set direction (1 or 0)
            vTaskDelay(pdMS_TO_TICKS(20)); // or use ets_delay_us(10);
            step(6400*4);
        }
        if (tz == 1){
            gpio_set_level(Z_DIR_PIN, 1); // Set direction (1 or 0)
            vTaskDelay(pdMS_TO_TICKS(20)); // or use ets_delay_us(10);
            step(6400*4);
        }
        // gpio_set_level(EnablePIN, 1);
        // if (tz == 0) {
        //     // ===== Screw (Forward) =====
        //     gpio_set_level(Z_DIR_PIN, 1);
        //         for (int i = 0; i < 6400; i++) {
        //         step_pulse(Z_STEP_PIN);
        //     }

        //     printf("Screw: forward\n");    
        //     gpio_set_level(PIN1, 1);
        //     gpio_set_level(PIN2, 0);
        //     vTaskDelay(pdMS_TO_TICKS(2000)); // run for 2 sec
        // } else {
        //     // ===== Unscrew (Backward) =====
        //     gpio_set_level(Z_DIR_PIN, 0);
        //         for (int i = 0; i < 6400; i++) {
        //         step_pulse(Z_STEP_PIN);
        //     }
        //     printf("Unscrew: backward\n");
        //     gpio_set_level(PIN1, 0);
        //     gpio_set_level(PIN2, 1);
        //     vTaskDelay(pdMS_TO_TICKS(2000)); // run for 2 sec
        // }


        printf("\nReached (%d, %d)\n", current_x_mm, current_y_mm);
    }
}

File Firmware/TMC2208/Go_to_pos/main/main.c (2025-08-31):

#include <stdio.h>
#include "esp_log.h"
#include <inttypes.h>
#include "driver/uart.h"
#include "freertos/FreeRTOS.h"
#include "freertos/task.h"
#include "driver/gpio.h"

#define TMC_TX 17
#define TMC_RX 16
#define REG_IHOLD_IRUN   0x10
#define REG_CHOPCONF     0x6C
#define BUF_SIZE 128

#define STEP_PIN GPIO_NUM_12
#define DIR_PIN  GPIO_NUM_14
#define LIM_SWITCH_PIN  GPIO_NUM_15

#define STEP_HIGH_TIME_uS 5
#define STEP_TOTAL_TIME_uS 30
#define PulleyRadius 6.36

#define PI 3.14159265358979324

static const char *TAG = "TMC2208";
static uart_port_t g_uart_num;

void tmc_uart_init(uart_port_t uart_num, int tx_pin, int rx_pin) {
    g_uart_num = uart_num;
    const uart_config_t uart_config = {
        .baud_rate = 115200,
        .data_bits = UART_DATA_8_BITS,
        .parity    = UART_PARITY_DISABLE,
        .stop_bits = UART_STOP_BITS_1,
        .flow_ctrl = UART_HW_FLOWCTRL_DISABLE
    };
    uart_driver_install(uart_num, BUF_SIZE, BUF_SIZE, 0, NULL, 0);
    uart_param_config(uart_num, &uart_config);
    uart_set_pin(uart_num, tx_pin, rx_pin, UART_PIN_NO_CHANGE, UART_PIN_NO_CHANGE);
}

void setup_stepper_pins() {
    // Configure stepper driver output pins
    gpio_config_t io_conf_out = {
        .intr_type = GPIO_INTR_DISABLE,
        .mode = GPIO_MODE_OUTPUT,
        .pin_bit_mask = (1ULL << STEP_PIN) | (1ULL << DIR_PIN),  
                    
        .pull_down_en = 0,
        .pull_up_en = 0
    };
    gpio_config(&io_conf_out);

    // Configure limit switch input pin with pull-up
    gpio_config_t io_conf_in = {
        .intr_type = GPIO_INTR_DISABLE,
        .mode = GPIO_MODE_INPUT,
        .pin_bit_mask = (1ULL << LIM_SWITCH_PIN),
        .pull_down_en = 0,
        .pull_up_en = 1 // Use pull-up if switch connects to GND when pressed
    };
    
    gpio_config(&io_conf_in);


}

uint8_t tmc_crc(uint8_t *data, int length) {
    uint8_t crc = 0;
    for (int i = 0; i < length; i++) {
        crc ^= data[i];
        for (int j = 0; j < 8; j++) {
            if (crc & 0x80)
                crc = (crc << 1) ^ 0x07;
            else
                crc <<= 1;
        }
    }
    return crc;
}

void tmc_write_reg(uint8_t reg, uint32_t value) {
    uint8_t packet[8];
    packet[0] = 0x05;
    packet[1] = 0x00;
    packet[2] = reg | 0x80; 
    packet[3] = (value >> 24) & 0xFF;
    packet[4] = (value >> 16) & 0xFF;
    packet[5] = (value >> 8) & 0xFF;
    packet[6] = value & 0xFF;
    packet[7] = tmc_crc(packet, 7);

    uart_write_bytes(g_uart_num, (const char*)packet, 8);
}

uint32_t tmc_read_reg(uint8_t reg) {
    uint8_t packet[4];
    packet[0] = 0x05;
    packet[1] = 0x00;
    packet[2] = reg & 0x7F;
    packet[3] = tmc_crc(packet, 3);

    uart_write_bytes(g_uart_num, (const char*)packet, 4);

    uint8_t resp[8];
    int len = uart_read_bytes(g_uart_num, resp, 8, 100 / portTICK_PERIOD_MS);
    if (len == 8 && resp[7] == tmc_crc(resp, 7)) {
        return (resp[3] << 24) | (resp[4] << 16) | (resp[5] << 8) | resp[6];
    }
    ESP_LOGW(TAG, "Bad read response");
    return 0;
}

// Set motor to 256 microstepping
void tmc_set_microstepping() {
    uint32_t chopconf = tmc_read_reg(REG_CHOPCONF);

    // Clear MRES bits [24..27]
    chopconf &= ~(0xF << 24);
    // Set to 256 microsteps
    chopconf |= (0x0 << 24);

    tmc_write_reg(REG_CHOPCONF, chopconf);
}

// Set current (hold, run, delay)
void tmc_set_current(uint8_t ihold, uint8_t irun, uint8_t iholddelay) {
    uint32_t val = (ihold & 0x1F) | ((irun & 0x1F) << 8) | ((iholddelay & 0x1F) << 16);
    tmc_write_reg(REG_IHOLD_IRUN, val);
}

void single_step() {
    gpio_set_level(STEP_PIN, 1);
    esp_rom_delay_us(STEP_HIGH_TIME_uS);
    gpio_set_level(STEP_PIN, 0);
    esp_rom_delay_us(100 - STEP_HIGH_TIME_uS);
}

void home() {
    gpio_set_level(DIR_PIN, 0); // Move towards switch
    while (gpio_get_level(LIM_SWITCH_PIN) == 1) {
        single_step(STEP_PIN);
        //vTaskDelay(pdMS_TO_TICKS(1)); // allow FreeRTOS to switch tasks
    }
    //vTaskDelete(NULL);
}


void step(int no_steps) {
    int accel_steps = 6400;
    int decel_steps = accel_steps;
    if (no_steps<accel_steps){
        accel_steps=no_steps/2;
        decel_steps=accel_steps;
    }
    int const_steps = no_steps - accel_steps - decel_steps;
    if (const_steps<0){
        const_steps=0;
        accel_steps=no_steps/2;
        decel_steps=accel_steps;
    }
    // Define min and max total step time (in microseconds)
    int min_step_time = 30;  // Fastest (small delay between steps)
    int max_step_time = 150; // Slowest (long delay between steps)

    int total_steps=0;

    // Acceleration Phase
    for (int i = 0; i < accel_steps; i++) {
        int step_time = max_step_time - ((max_step_time - min_step_time) * i / accel_steps);
        gpio_set_level(STEP_PIN, 1);
        esp_rom_delay_us(STEP_HIGH_TIME_uS);
        gpio_set_level(STEP_PIN, 0);
        esp_rom_delay_us(step_time - STEP_HIGH_TIME_uS);
        total_steps++;
    }

    // Constant Speed Phase
    for (int i = 0; i < const_steps; i++) {
        gpio_set_level(STEP_PIN, 1);
        esp_rom_delay_us(STEP_HIGH_TIME_uS);
        gpio_set_level(STEP_PIN, 0);
        esp_rom_delay_us(min_step_time - STEP_HIGH_TIME_uS);
        total_steps++;
    }

    // Deceleration Phase
    for (int i = 0; i < decel_steps; i++) {
        int step_time = min_step_time + ((max_step_time - min_step_time) * i / decel_steps);
        gpio_set_level(STEP_PIN, 1);
        esp_rom_delay_us(STEP_HIGH_TIME_uS);
        gpio_set_level(STEP_PIN, 0);
        esp_rom_delay_us(step_time - STEP_HIGH_TIME_uS);
        total_steps++;
    }

    printf("Total steps taken = %d\n" ,total_steps);
}

int uart_read_int() {
    char input[32] = {0};
    int idx = 0;
    uint8_t ch;

    while (idx < sizeof(input) - 1) {
        int len = uart_read_bytes(UART_NUM_0, &ch, 1, pdMS_TO_TICKS(10000));
        if (len > 0) {
            if (ch == '\n' || ch == '\r') {
                break;
            }
            input[idx++] = ch;
            uart_write_bytes(UART_NUM_0, (const char *)&ch, 1);  // Echo back
        }
    }
    input[idx] = '\0';
    return atoi(input);
}
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

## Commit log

2025-07-28 homing and other projects
2025-07-30 positioning with homing
2025-08-01 fixing the step_func folder issue
    [go_to_pos.c]
2025-08-02 Fixed the bug in positioning code
    [go_to_pos.c]
2025-08-04 Added Schematic for MP 1584 5V and 12V
    [PCB_Gantry.kicad_pcb, PCB_Gantry.kicad_sch, untitled.kicad2_sch.kicad_sch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]
2025-08-06 schematic n footprints of drv n esp32
2025-08-06 Added Schematic
    [DRV8825_STEPPER_MOTOR_DRIVER_CARRIER.step, F2.kicad_sch, PCB_Gantry.kicad_sch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]
2025-08-11 Some Stl files
    [x-moteur - support moteur.stl, x-moteur - support paliers L.stl, x-moteur - support_palier_R.stl]
2025-08-15 Updated Schematic with labels
    [F2.kicad_sch, PCB_Gantry.kicad_sch]
2025-08-15 fixed the homing error
    [homing.c]
2025-08-17 Limit switch test
2025-08-21 Added Some Footprints
    [DRV8825_STEPPER_MOTOR_DRIVER_CARRIER.step, F2.kicad_sch, PCB_Gantry.kicad_sch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]
2025-08-31 fixed homing in total positioning
    [total_positioning.c]
2025-08-31 added sample code for TMC2208, awaiting testing
2025-09-04 Added basic Screwdriver Code
2025-09-06 Fully functional 3-axis code for gantry
2025-09-06 Added Stepper Motor Driver Docs
2025-09-06 Screenshots of CAD model
2025-09-06 Added PCB files and readme
    [DRV8825_STEPPER_MOTOR_DRIVER_CARRIER.step, F2.kicad_sch, PCB.kicad_pcb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]
